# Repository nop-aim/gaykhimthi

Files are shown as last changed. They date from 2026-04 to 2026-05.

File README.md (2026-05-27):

# 🦯 Gậy Thông Minh – Smart Cane

> Thiết bị hỗ trợ người khiếm thị tích hợp AI nhận diện vật cản, cảnh báo âm thanh theo thời gian thực và nút SOS khẩn cấp.

---

## Mục lục

1. [Tổng quan dự án](#1-tổng-quan-dự-án)
2. [Kiến trúc hệ thống](#2-kiến-trúc-hệ-thống)
3. [Phần cứng](#3-phần-cứng)
4. [Phần mềm](#4-phần-mềm)
5. [Luồng hoạt động](#5-luồng-hoạt-động)
6. [Hướng dẫn cài đặt](#6-hướng-dẫn-cài-đặt)
7. [Cấu hình](#7-cấu-hình)
8. [Giao thức truyền thông](#8-giao-thức-truyền-thông)
9. [Xử lý lỗi và cơ chế an toàn](#9-xử-lý-lỗi-và-cơ-chế-an-toàn)
10. [Cấu trúc thư mục](#10-cấu-trúc-thư-mục)

---

## 1. Tổng quan dự án

**Gậy Thông Minh** là thiết bị hỗ trợ điều hướng cho người khiếm thị, hoạt động theo mô hình **Edge–Cloud Hybrid**:

- **Trên gậy (Edge – XIAO ESP32-S3):** chụp ảnh liên tục, đọc cảm biến siêu âm, phát âm thanh cảnh báo qua loa I2S, theo dõi GPS và gửi SMS khẩn cấp.
- **Máy tính xách tay / máy chủ (Cloud – Python/Flask):** nhận ảnh từ ESP32, chạy mô hình YOLO11 để nhận diện vật cản, trả kết quả cảnh báo bằng tiếng Việt và phát âm thanh TTS trên màn hình.

Hai tầng kết nối với nhau qua WiFi nội bộ bằng HTTP REST.

---

## 2. Kiến trúc hệ thống

```
┌──────────────────────────────────────────────────────────┐
│                  XIAO ESP32-S3 (trên gậy)                │
│                                                          │
│  ┌──────────┐   JPEG    ┌──────────────────────────────┐ │
│  │ Camera   │ ────────► │  TaskCamera (Core 0)         │ │
│  │ OV2640   │           │  POST /upload → nhận WARNING │ │
│  └──────────┘           └──────────────────────────────┘ │
│                                        │ mutex           │
│  ┌──────────┐  I2C      ┌──────────────▼──────────────┐  │
│  │ Siêu âm  │ ────────► │  TaskSensors (Core 1)       │  │
│  │ SRF02    │           │  Đọc khoảng cách + playAlert│  │
│  └──────────┘           └─────────────────────────────┘  │
│                                                          │
│  ┌──────────┐  UART     ┌──────────────────────────────┐ │
│  │  GPS     │ ────────► │  TaskGPS (Core 1)            │ │
│  │ NEO-6M   │           │  POST /gps mỗi 5 giây        │ │
│  └──────────┘           └──────────────────────────────┘ │
│                                                          │
│  ┌──────────┐  GPIO     ┌──────────────────────────────┐ │
│  │ Nút SOS  │ ────────► │  Gửi SMS + playAlert(SOS)    │ │
│  └──────────┘           └──────────────────────────────┘ │
│                                                          │
│  ┌──────────┐  UART     ┌──────────────────────────────┐ │
│  │ SIM A7680│ ◄──────── │  sendSMS() + sendAT()        │ │
│  └──────────┘           └──────────────────────────────┘ │
└──────────────────────────────────────────────────────────┘
                        │ WiFi (HTTP)
                        ▼
┌──────────────────────────────────────────────────────────┐
│              Server Python / Flask (máy tính)            │
│                                                          │
│  POST /upload ──► img_queue ──► ai_processing_thread     │
│                                  │                       │
│                                  ├─ YOLO11 inference     │
│                                  ├─ Xác định vị trí +    │
│                                  │  khoảng cách          │
│                                  ├─ gTTS → pygame TTS    │
│                                  └─ Trả [[WARNING_TEXT]] │
│                                                          │
│  POST /gps ─────────────────────► Lưu / hiển thị GPS     │
└──────────────────────────────────────────────────────────┘
```

---

## 3. Phần cứng

### 3.1 Danh sách linh kiện

| Linh kiện | Model | Giao tiếp | Vai trò |
|---|---|---|---|
| Vi điều khiển | Seeed XIAO ESP32-S3 Sense | — | Não xử lý trung tâm |
| Camera | OV2640 (tích hợp sẵn) | DVP parallel | Chụp ảnh QVGA JPEG |
| Cảm biến siêu âm | SRF02 (I2C, addr `0x70`) | I2C | Đo khoảng cách < 2 m |
| Module GPS | NEO-6M (hoặc tương đương) | UART1 (RX=3, TX=2) | Lấy toạ độ thời gian thực |
| Module SIM | SIM A7680C (4G LTE) | UART2 (RX=4, TX=1) | Gửi SMS SOS |
| Loa I2S | MAX98357A hoặc tương đương | I2S (BCK=7, WS=8, DATA=9) | Phát âm thanh cảnh báo |
| Nút bấm | Nút thường hở (NO) | GPIO 44 (INPUT_PULLUP) | Kích hoạt SOS |

### 3.2 Sơ đồ chân (XIAO ESP32-S3)

| GPIO | Tên chân | Kết nối |
|---|---|---|
| 5 | SDA | I2C SDA (cảm biến siêu âm) |
| 6 | SCL | I2C SCL (cảm biến siêu âm) |
| 7 | I2S_BCK | Loa I2S – Bit Clock |
| 8 | I2S_WS | Loa I2S – Word Select (LRCK) |
| 9 | I2S_DATA | Loa I2S – Data |
| 44 | BUTTON | Nút SOS (GND khi nhấn) |
| 1 | TX2 | SIM A7680C RX |
| 4 | RX2 | SIM A7680C TX |
| 2 | TX1 | GPS TX |
| 3 | RX1 | GPS RX |

> **Lưu ý:** Camera OV2640 sử dụng các chân DVP cố định theo cấu hình XIAO ESP32-S3 Sense (D0–D7, XCLK, PCLK, VSYNC, HREF, SIOD, SIOC) — không thay đổi được.

---

## 4. Phần mềm

### 4.1 Firmware ESP32 (`esp32_improved.ino`)

Viết bằng **Arduino framework** cho ESP32, sử dụng **FreeRTOS** để chạy đa nhiệm trên 2 nhân CPU.

| Task | Nhân | Stack | Chức năng |
|---|---|---|---|
| `TaskCamera` | Core 0 | 16 KB | Chụp ảnh → POST lên server → nhận cảnh báo AI |
| `TaskSensors` | Core 1 | 10 KB | Đọc siêu âm I2C, xử lý nút SOS, phát âm thanh |
| `TaskGPS` | Core 1 | 8 KB | Đọc GPS NMEA, gửi toạ độ lên server mỗi 5 giây |

**Thư viện Arduino cần thiết:**

- `esp_camera.h` — driver camera ESP32
- `WiFi.h` + `HTTPClient.h` — kết nối mạng
- `Wire.h` — giao tiếp I2C với cảm biến siêu âm
- `TinyGPS++` — giải mã dữ liệu NMEA từ module GPS
- `AudioTools` — tạo sóng sin và xuất I2S cho loa

### 4.2 Server AI (`serve_2.py`)

Viết bằng **Python 3**, chạy trên máy tính trong cùng mạng WiFi.

**Thư viện Python cần thiết:**

- `flask` — HTTP server nhận ảnh từ ESP32
- `ultralytics` — chạy mô hình YOLO11
- `opencv-python` (`cv2`) — giải mã JPEG, hiển thị kết quả
- `numpy` — xử lý mảng ảnh
- `gTTS` — chuyển text thành giọng nói tiếng Việt
- `pygame` — phát âm thanh TTS
- `threading`, `queue` — xử lý bất đồng bộ

---

## 5. Luồng hoạt động

### 5.1 Nhận diện vật cản bằng AI (Camera + YOLO)

```
ESP32                              Server (Flask + YOLO)
  │                                        │
  ├─ Chụp ảnh QVGA JPEG (300ms/lần)        │
  ├─ POST /upload (raw bytes)  ──────────► │
  │                                        ├─ Giải mã JPEG → frame
  │                                        ├─ YOLO11 inference (conf=0.5)
  │                                        ├─ Lọc class: người, xe, ghế, bàn...
  │                                        ├─ Tính vị trí (trái/trước/phải)
  │                                        ├─ Tính khoảng cách (% diện tích bbox)
  │                                        ├─ Tạo chuỗi: "Có ô tô phía trước, rất gần"
  │                                        ├─ gTTS phát tiếng (nếu cảnh báo mới)
  │ ◄────────────────── [[WARNING_TEXT]]   │
  ├─ Cập nhật `hasObstacle_AI`             │
  ├─ Phát beep I2S (1500Hz, 400ms)         │
```

**Logic xác định khoảng cách** (dựa vào tỉ lệ diện tích bounding box / tổng diện tích frame):

| Tỉ lệ diện tích | Cảnh báo |
|---|---|
| > 35% | "rất gần"|
| 12% – 35% | "đang đến gần" |
| < 12% | "ở xa" |

**Các lớp vật thể được nhận diện:**

| ID COCO | Tên tiếng Anh | Tên tiếng Việt|
|---|---|---|
| 0 | person | người |
| 1 | bicycle | xe đạp |
| 2 | car | ô tô |
| 3 | motorcycle | xe máy |
| 5 | bus | xe buýt |
| 7 | truck | xe tải |
| 56 | chair | ghế |
| 60 | dining table | bàn |

### 5.2 Cảm biến siêu âm (khoảng cách gần)

- Đọc liên tục qua I2C (địa chỉ `0x70`)
- Áp dụng bộ lọc trung bình trượt 5 mẫu để giảm nhiễu
- Nếu khoảng cách trung bình < **120 cm**: kích hoạt cờ `hasObstacle_US`
- Phát âm thanh beep khẩn (2000 Hz, 150 ms) — **ưu tiên cao hơn cảnh báo AI**

### 5.3 SOS khẩn cấp

1. Người dùng nhấn nút GPIO 44
2. Debounce 3 giây (tránh gửi nhiều lần)
3. Gửi SMS đến số `SOS_PHONE` qua SIM A7680C:
   ```
   SOS! Vi tri: https://maps.google.com/?q=<lat>,<lng>
   ```
4. Phát âm thanh cảnh báo (1500 Hz, 1000 ms)

### 5.4 GPS tracking

- Task `TaskGPS` chạy riêng trên Core 1, không block cảm biến siêu âm
- Giải mã dữ liệu NMEA từ module GPS qua UART1
- Cần tối thiểu **4 vệ tinh** để coi là tín hiệu hợp lệ
- Gửi toạ độ JSON lên `POST /gps` mỗi **5 giây**:
  ```json
  {"lat": 10.762622, "lng": 106.660172}
  ```

---

## 6. Hướng dẫn cài đặt

### 6.1 Cài đặt Server (máy tính)

```bash
# 1. Tạo môi trường ảo Python
python -m venv venv
source venv/bin/activate       # Linux/macOS
venv\Scripts\activate          # Windows

# 2. Cài đặt thư viện
pip install flask ultralytics opencv-python gTTS pygame numpy

# 3. Tải mô hình YOLO11s (tự động tải khi chạy lần đầu)
#    Hoặc tải thủ công: https://github.com/ultralytics/assets/releases
#    Đặt file yolo11s.pt cùng thư mục với serve_2.py

# 4. Chạy server
python serve_2.py
# Server sẽ lắng nghe tại http://0.0.0.0:5000
```

### 6.2 Nạp firmware ESP32

**Yêu cầu:**
- Arduino IDE 2.x hoặc VS Code + PlatformIO
- Board: `Seeed XIAO ESP32S3` (cài qua Board Manager)

**Thư viện cần cài (Library Manager):**
- `TinyGPS++` by Mikal Hart
- `arduino-audio-tools` by pschatzmann

**Bước nạp:**
1. Mở `esp32_improved.ino` trong Arduino IDE
2. Cập nhật cấu hình mạng (xem mục 7)
3. Chọn **Board:** `XIAO_ESP32S3` và **Port** tương ứng
4. Nhấn **Upload**

---

## 7. Cấu hình

Tất cả cấu hình nằm ở đầu file `esp32_improved.ino`:

```cpp
// ── Mạng & Server ────────────────────────────────────────
const char* serverUrl = "http://192.168.1.135:5000/upload"; // IP máy chủ
const char* gpsUrl    = "http://192.168.1.135:5000/gps";    // Endpoint GPS
const char* ssid      = "Tên_WiFi";                         // SSID WiFi
const char* password  = "Mật_khẩu_WiFi";                   // Mật khẩu WiFi

// ── SOS ──────────────────────────────────────────────────
const char* SOS_PHONE = "09xxxxxxxx";                       // Số điện thoại nhận SMS

// ── Ngưỡng cảm biến siêu âm ──────────────────────────────
// Trong TaskSensors: (sum / filterSamples) < 120
// 120 tương đương ~1.2 m (đơn vị cảm biến SRF02: cm)
// Thay đổi giá trị này để điều chỉnh độ nhạy

// ── Tần suất chụp ảnh ────────────────────────────────────
vTaskDelay(300 / portTICK_PERIOD_MS); // 300ms ≈ ~3 fps
```

**Tìm IP máy chủ** (máy chạy `serve_2.py`):
```bash
# Linux/macOS
ip addr show | grep "inet "

# Windows
ipconfig
```

---

## 8. Giao thức truyền thông

### POST `/upload` — Gửi ảnh từ ESP32

| Thuộc tính | Giá trị |
|---|---|
| Method | POST |
| Content-Type | `image/jpeg` |
| Body | Raw JPEG bytes |
| Response | `[[CLEAR]]` hoặc `[[Có ô tô phía trước, rất gần]]` |

### POST `/gps` — Gửi toạ độ GPS

| Thuộc tính | Giá trị |
|---|---|
| Method | POST |
| Content-Type | `application/json` |
| Body | `{"lat": 10.762622, "lng": 106.660172}` |

---

## 9. Xử lý lỗi và cơ chế an toàn

| Vấn đề | Giải pháp đã triển khai |
|---|---|
| WiFi mất kết nối | `connectWiFi()` tự động thử lại; watchdog kiểm tra mỗi 30 giây trong `loop()` |
| HTTP timeout | Mọi request đều có timeout 3 giây (`HTTP_TIMEOUT_MS`) |
| Race condition giữa 2 core | FreeRTOS mutex (`obstacleMutex`) bảo vệ biến dùng chung |
| GPS block siêu âm | `TaskGPS` chạy tách biệt trên Core 1 |
| Nút SOS nhấn nhiều lần | Debounce phần mềm 3 giây (`lastSosTap`) |
| Loa block CPU | `playAlert()` dùng timeout + `taskYIELD()` thay vì busy-wait |
| FreeRTOS watchdog reset | Thay `delay()` bằng `vTaskDelay()` trong tất cả task |
| SIM không nhận lệnh | `readSIM()` chờ prompt `>` trước khi gửi nội dung SMS |
| Bộ lọc nhiễu siêu âm | Trung bình trượt 5 mẫu (`filterSamples = 5`) |
| TTS phát liên tục | Cooldown 3 giây (`last_speak_time`) giữa các lần phát |
| Hàng đợi ảnh tràn | `img_queue` kích thước 1, tự xoá frame cũ khi đầy |

---

## 10. Cấu trúc thư mục

```
smart-cane/
├── esp32_improved.ino   # Firmware XIAO ESP32-S3
├── serve_2.py           # Server AI Flask + YOLO11
├── yolo11s.pt           # Mô hình YOLO11s (tải riêng)
└── README.md            # Tài liệu này
```

---

## Tác giả & Giấy phép

Dự án được phát triển nhằm mục đích hỗ trợ người khiếm thị. Mã nguồn mở để học tập và cải tiến.

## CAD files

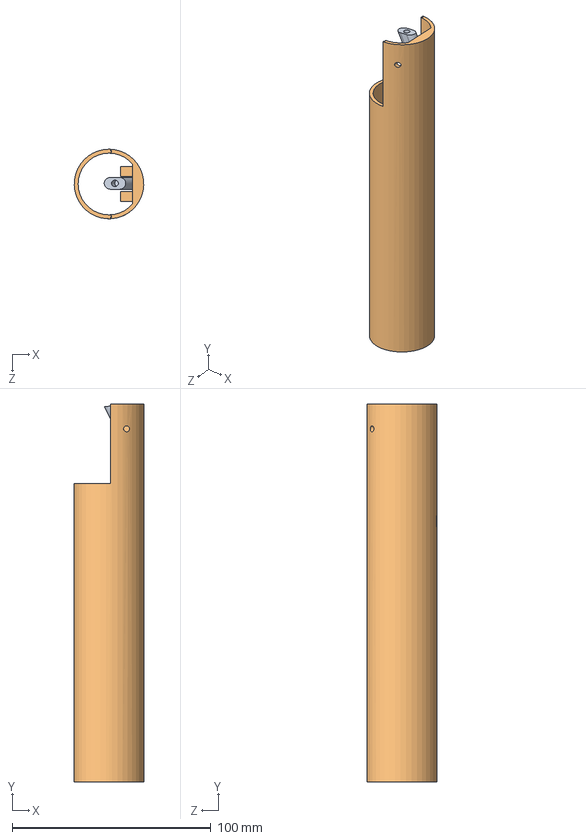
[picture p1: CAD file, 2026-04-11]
STL/Assem1.SLDASM
35.0 x 190.0 x 35.0 mm
end_2
gy

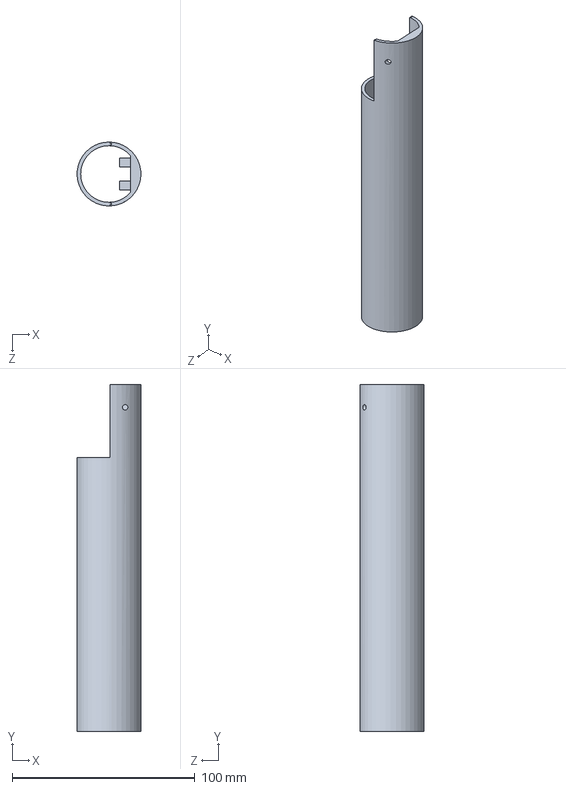
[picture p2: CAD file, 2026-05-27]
STL/end_2.SLDPRT
35.0 x 190.0 x 35.0 mm

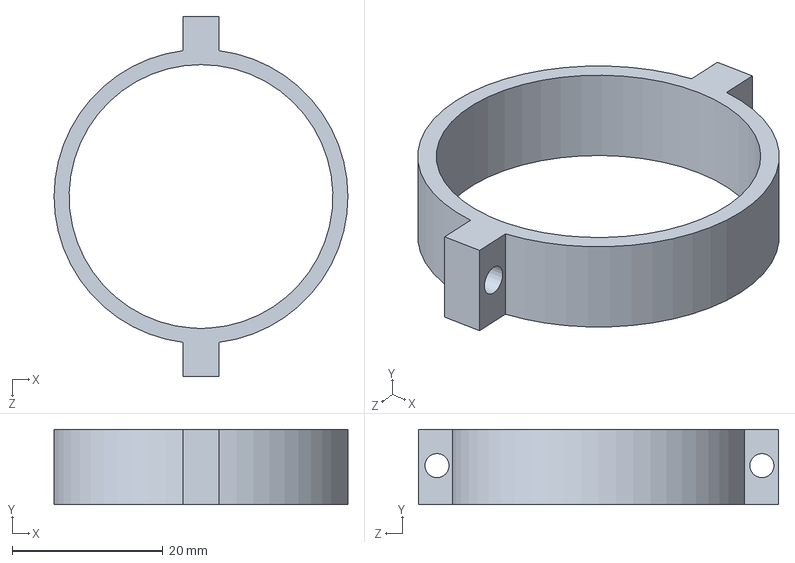
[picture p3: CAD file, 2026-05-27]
STL/khopnoi.SLDPRT
39.0 x 10.0 x 47.8 mm

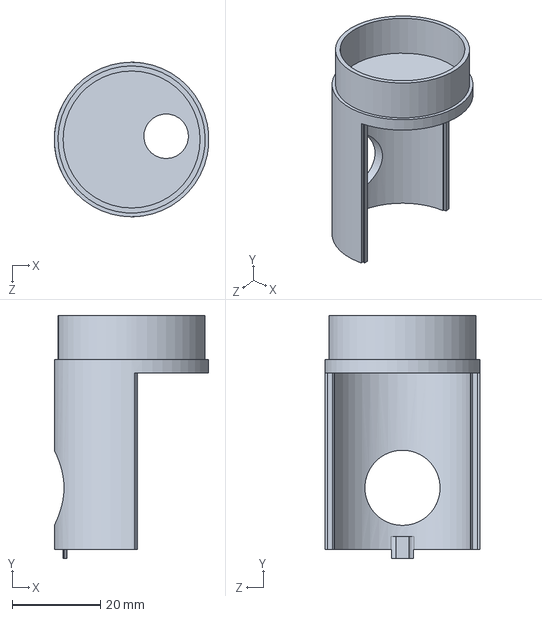
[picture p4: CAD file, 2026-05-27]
STL/end_khopnoi.SLDPRT
35.0 x 55.0 x 35.0 mm

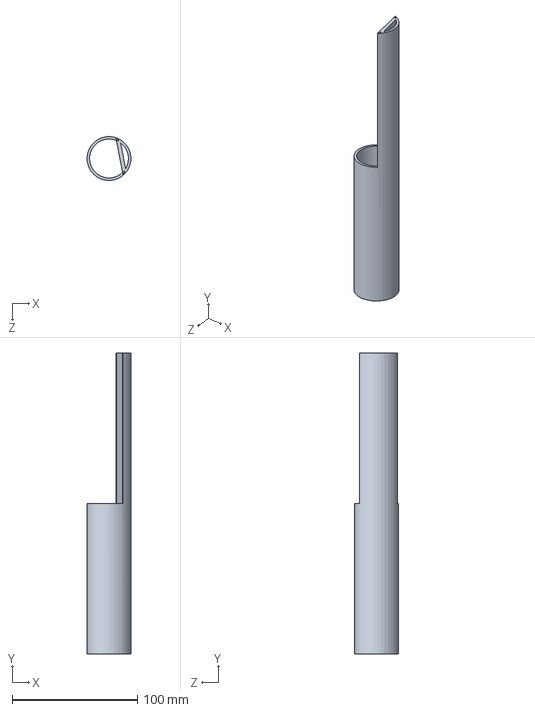
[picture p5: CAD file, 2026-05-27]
STL/header.SLDPRT
35.0 x 240.0 x 35.0 mm

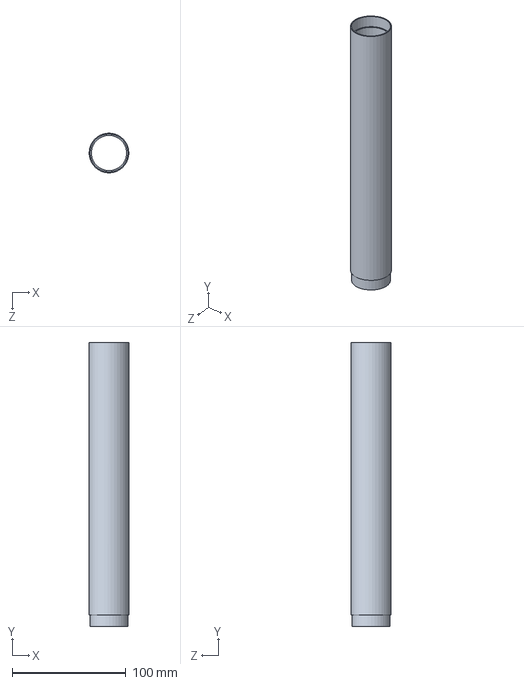
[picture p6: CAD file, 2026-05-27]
STL/body.SLDPRT
35.0 x 250.0 x 35.0 mm

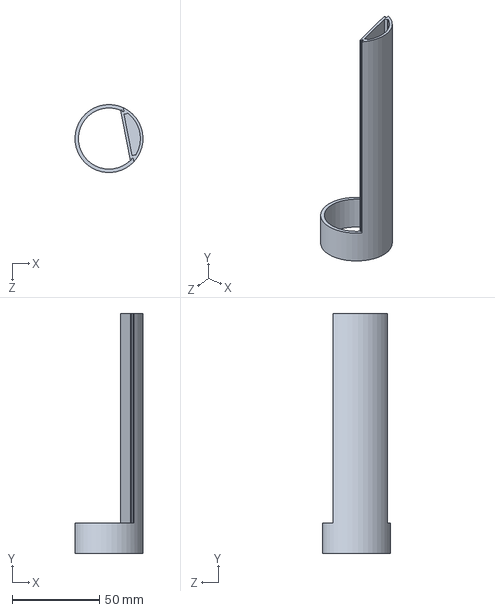
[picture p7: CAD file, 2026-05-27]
STL/header_cap_napday.SLDPRT
39.0 x 137.5 x 38.9 mm

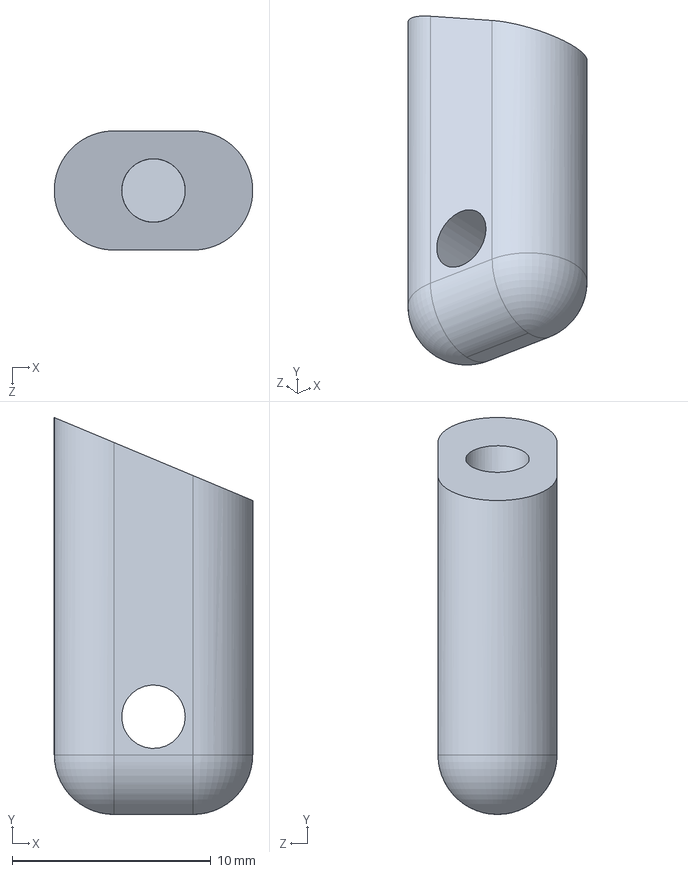
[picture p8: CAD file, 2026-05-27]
STL/gy.SLDPRT
10.0 x 20.0 x 6.00 mm

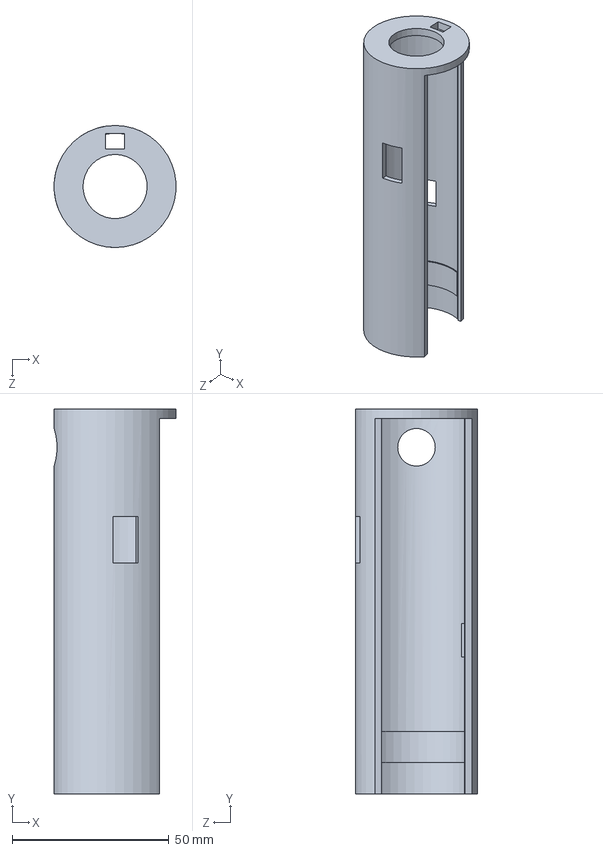
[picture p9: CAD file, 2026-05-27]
STL/header_cap.SLDPRT
38.9 x 123.0 x 39.0 mm

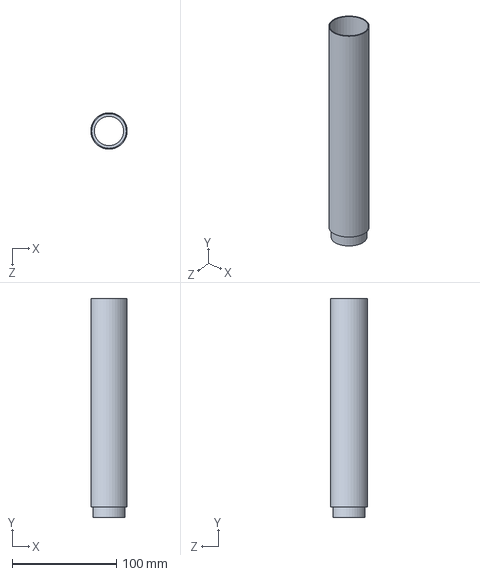
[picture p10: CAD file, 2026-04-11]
STL/bodyhead.SLDPRT
34.9 x 210.0 x 35.0 mm

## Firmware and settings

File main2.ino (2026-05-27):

#include "esp_camera.h"
#include <WiFi.h>
#include <HTTPClient.h>
#include <Wire.h>
#include <TinyGPS++.h>
#include "AudioTools.h"

// ════════════════════════════════════════════════════════════════
//  CẤU HÌNH
// ════════════════════════════════════════════════════════════════
const char* serverUrl = "http://192.168.1.135:5000/upload";
const char* gpsUrl    = "http://192.168.1.135:5000/gps";
const char* ssid      = "TMaii";
const char* password  = "16071779@";
const char* SOS_PHONE = "0397969813";

#define PIN_SDA        5
#define PIN_SCL        6
#define PIN_I2S_BCK    7
#define PIN_I2S_WS     8
#define PIN_I2S_DATA   9
#define PIN_BUTTON    44
#define HTTP_TIMEOUT_MS 3000    // [FIX 1] Timeout cho mọi request HTTP

// ════════════════════════════════════════════════════════════════
//  CAMERA PINS (XIAO ESP32-S3 SENSE)
// ════════════════════════════════════════════════════════════════
#define PWDN_GPIO_NUM  -1
#define RESET_GPIO_NUM -1
#define XCLK_GPIO_NUM  10
#define SIOD_GPIO_NUM  40
#define SIOC_GPIO_NUM  39
#define Y9_GPIO_NUM    48
#define Y8_GPIO_NUM    11
#define Y7_GPIO_NUM    12
#define Y6_GPIO_NUM    14
#define Y5_GPIO_NUM    16
#define Y4_GPIO_NUM    18
#define Y3_GPIO_NUM    17
#define Y2_GPIO_NUM    15
#define VSYNC_GPIO_NUM 38
#define HREF_GPIO_NUM  47
#define PCLK_GPIO_NUM  13

// ════════════════════════════════════════════════════════════════
//  OBJECTS
// ════════════════════════════════════════════════════════════════
HardwareSerial SIM(2);
HardwareSerial GPS_Serial(1);
TinyGPSPlus gps;
I2SStream i2s;
SineWaveGenerator<int16_t> sineWave;
GeneratedSoundStream<int16_t> sound(sineWave);

// [FIX 3] Mutex bảo vệ biến dùng chung giữa 2 core
SemaphoreHandle_t obstacleMutex;
volatile bool hasObstacle_AI = false;
volatile bool hasObstacle_US = false;
String ai_warning_msg = "";
String currentGPS     = "0,0";

// Bộ lọc siêu âm
const int filterSamples = 5;
int distanceHistory[filterSamples] = {0};
int historyIndex = 0;

// Timers
unsigned long lastGPSSend  = 0;
unsigned long lastSosTap   = 0;   // [FIX 4] debounce SOS

// ════════════════════════════════════════════════════════════════
//  SETUP
// ════════════════════════════════════════════════════════════════
void setup() {
  Serial.begin(115200);
  delay(2000);
  Serial.println("\n=== KHOI DONG GAY THONG MINH (XIAO S3) ===");

  // [FIX 3] Tạo mutex trước mọi task
  obstacleMutex = xSemaphoreCreateMutex();

  // 1. I2C
  Wire.begin(PIN_SDA, PIN_SCL);
  Wire.setClock(100000);

  // 2. SIM A7680C
  SIM.begin(115200, SERIAL_8N1, 4, 1);
  delay(2000);
  sendAT("AT");
  sendAT("AT+CPIN?");
  sendAT("AT+CSQ");
  sendAT("AT+CNMP=38");
  sendAT("AT+AUTOCONN=1");
  delay(3000);

  // 3. GPS
  GPS_Serial.begin(9600, SERIAL_8N1, 3, 2);
  Serial.println("Dang cho GPS fix...");
  unsigned long start = millis();
  while (millis() - start < 20000) {
    while (GPS_Serial.available()) gps.encode(GPS_Serial.read());
    if (gps.location.isValid() && gps.satellites.value() >= 4) {
      Serial.printf("\n[ OK ] GPS: %.6f, %.6f (%d sats)\n",
                    gps.location.lat(), gps.location.lng(), gps.satellites.value());
      break;
    }
    Serial.print(".");
    delay(500);
  }

  // 4. Camera
  camera_config_t config;
  config.ledc_channel = LEDC_CHANNEL_0;
  config.ledc_timer   = LEDC_TIMER_0;
  config.pin_d0 = Y2_GPIO_NUM; config.pin_d1 = Y3_GPIO_NUM;
  config.pin_d2 = Y4_GPIO_NUM; config.pin_d3 = Y5_GPIO_NUM;
  config.pin_d4 = Y6_GPIO_NUM; config.pin_d5 = Y7_GPIO_NUM;
  config.pin_d6 = Y8_GPIO_NUM; config.pin_d7 = Y9_GPIO_NUM;
  config.pin_xclk    = XCLK_GPIO_NUM;  config.pin_pclk  = PCLK_GPIO_NUM;
  config.pin_vsync   = VSYNC_GPIO_NUM; config.pin_href  = HREF_GPIO_NUM;
  config.pin_sscb_sda = SIOD_GPIO_NUM; config.pin_sscb_scl = SIOC_GPIO_NUM;
  config.pin_pwdn  = PWDN_GPIO_NUM;    config.pin_reset = RESET_GPIO_NUM;
  config.xclk_freq_hz = 20000000;
  config.frame_size   = FRAMESIZE_QVGA;
  config.pixel_format = PIXFORMAT_JPEG;
  config.grab_mode    = CAMERA_GRAB_LATEST;
  config.fb_count     = 2;
  config.jpeg_quality = 12;

  esp_err_t err = esp_camera_init(&config);
  if (err == ESP_OK) {
    sensor_t* s = esp_camera_sensor_get();
    s->set_hmirror(s, 1);
    s->set_vflip(s, 0);
    Serial.println("[ OK ] Camera san sang.");
  } else {
    Serial.printf("[ FAIL ] Camera loi: 0x%x\n", err);
  }

  // 5. WiFi
  pinMode(PIN_BUTTON, INPUT_PULLUP);
  connectWiFi();

  // 6. Loa I2S
  auto info = i2s.defaultConfig();
  info.sample_rate = 44100;
  info.pin_bck     = PIN_I2S_BCK;
  info.pin_ws      = PIN_I2S_WS;
  info.pin_data    = PIN_I2S_DATA;
  i2s.begin(info);

  // Tạo tasks — Stack size tăng thêm do thêm xử lý
  xTaskCreatePinnedToCore(TaskCamera,  "TaskCam",  16000, NULL, 1, NULL, 0);
  xTaskCreatePinnedToCore(TaskSensors, "TaskSens", 10000, NULL, 1, NULL, 1);
  xTaskCreatePinnedToCore(TaskGPS,     "TaskGPS",   8000, NULL, 1, NULL, 1);
}

// ════════════════════════════════════════════════════════════════
//  [FIX 5] Tự động kết nối lại WiFi
// ════════════════════════════════════════════════════════════════
void connectWiFi() {
  if (WiFi.status() == WL_CONNECTED) return;
  WiFi.begin(ssid, password);
  Serial.print("Connecting WiFi");
  int retry = 0;
  while (WiFi.status() != WL_CONNECTED && retry < 20) {
    delay(500);
    Serial.print(".");
    retry++;
  }
  if (WiFi.status() == WL_CONNECTED)
    Serial.println("\n[ OK ] IP: " + WiFi.localIP().toString());
  else
    Serial.println("\n[ WARN ] WiFi timeout, se thu lai sau.");
}

// ════════════════════════════════════════════════════════════════
//  CORE 0: CAMERA & UPLOAD
// ════════════════════════════════════════════════════════════════
void TaskCamera(void* p) {
  for (;;) {
    // [FIX 5] Kiểm tra và reconnect WiFi nếu cần
    if (WiFi.status() != WL_CONNECTED) {
      Serial.println("!!! WiFi mat ket noi — dang thu lai...");
      connectWiFi();
      vTaskDelay(2000 / portTICK_PERIOD_MS);
      continue;
    }

    camera_fb_t* fb = esp_camera_fb_get();
    if (!fb) {
      Serial.println("!!! Camera Capture Failed");
      vTaskDelay(100 / portTICK_PERIOD_MS);
      continue;
    }

    HTTPClient http;
    http.begin(serverUrl);
    http.addHeader("Content-Type", "image/jpeg");
    http.setTimeout(HTTP_TIMEOUT_MS);   // [FIX 1]

    int httpCode = http.POST(fb->buf, fb->len);

    if (httpCode == 200) {
      String response = http.getString();
      int s = response.indexOf("[[");
      int e = response.indexOf("]]");
      if (s != -1 && e != -1) {
        String cleanRes = response.substring(s + 2, e);
        cleanRes.trim();

        // [FIX 3] Dùng mutex khi ghi biến dùng chung
        if (xSemaphoreTake(obstacleMutex, pdMS_TO_TICKS(10)) == pdTRUE) {
          if (cleanRes != "CLEAR") {
            ai_warning_msg  = cleanRes;
            hasObstacle_AI  = true;
          } else {
            hasObstacle_AI  = false;
          }
          xSemaphoreGive(obstacleMutex);
        }
      }
    } else if (httpCode < 0) {
      Serial.printf("!!! HTTP loi: %d\n", httpCode);
    }

    http.end();
    esp_camera_fb_return(fb);
    vTaskDelay(300 / portTICK_PERIOD_MS);
  }
}

// ════════════════════════════════════════════════════════════════
//  [FIX 2] CORE 1 - TASK GPS RIÊNG (không block siêu âm)
// ════════════════════════════════════════════════════════════════
void TaskGPS(void* p) {
  for (;;) {
    while (GPS_Serial.available() > 0) {
      if (gps.encode(GPS_Serial.read()) && gps.location.isValid()) {
        currentGPS = String(gps.location.lat(), 6) + "," + String(gps.location.lng(), 6);
      }
    }

    // Gửi GPS mỗi 5 giây
    if (millis() - lastGPSSend > 5000 && gps.location.isValid()
        && WiFi.status() == WL_CONNECTED) {
      HTTPClient httpGPS;
      httpGPS.begin(gpsUrl);
      httpGPS.addHeader("Content-Type", "application/json");
      httpGPS.setTimeout(HTTP_TIMEOUT_MS);  // [FIX 1]
      String payload = "{\"lat\":" + String(gps.location.lat(), 6) +
                       ",\"lng\":" + String(gps.location.lng(), 6) + "}";
      httpGPS.POST(payload);
      httpGPS.end();
      lastGPSSend = millis();
    }

    vTaskDelay(200 / portTICK_PERIOD_MS);
  }
}

// ════════════════════════════════════════════════════════════════
//  CORE 1: CẢM BIẾN SIÊU ÂM & ÂM THANH
// ════════════════════════════════════════════════════════════════
void TaskSensors(void* p) {
  for (;;) {
    // ── Siêu âm I2C ──────────────────────────────────────────────
    Wire.beginTransmission(0x70);
    Wire.write(0x51);
    Wire.endTransmission();
    vTaskDelay(70 / portTICK_PERIOD_MS);

    Wire.requestFrom(0x70, 2);
    if (Wire.available() >= 2) {
      int rawDist = (Wire.read() << 8) | Wire.read();
      if (rawDist > 0 && rawDist < 4000) { // lấy khoảng từ 0-4m
        distanceHistory[historyIndex] = rawDist;
        historyIndex = (historyIndex + 1) % filterSamples;
        long sum = 0;
        for (int i = 0; i < filterSamples; i++) sum += distanceHistory[i];
        if ((sum / filterSamples) < 120) { //120 là 2m
          // [FIX 3] mutex khi ghi
          if (xSemaphoreTake(obstacleMutex, pdMS_TO_TICKS(10)) == pdTRUE) {
            hasObstacle_US = true;
            xSemaphoreGive(obstacleMutex);
          }
        }
      }
    }

    // ── [FIX 4] Nút SOS có debounce 3 giây ──────────────────────
    if (digitalRead(PIN_BUTTON) == LOW) {
      unsigned long now = millis();
      if (now - lastSosTap > 3000) {
        lastSosTap = now;
        sendSMS(SOS_PHONE, "SOS! Vi tri: https://maps.google.com/?q=" + currentGPS);
        playAlert(1500, 1000);
      }
    }

    // ── Ưu tiên cảnh báo âm thanh ────────────────────────────────
    bool doUS = false, doAI = false;
    String warnCopy;

    // [FIX 3] Đọc cờ trong mutex, sau đó xử lý ngoài
    if (xSemaphoreTake(obstacleMutex, pdMS_TO_TICKS(10)) == pdTRUE) {
      if (hasObstacle_US) { doUS = true; hasObstacle_US = false; }
      else if (hasObstacle_AI) { doAI = true; warnCopy = ai_warning_msg; hasObstacle_AI = false; }
      xSemaphoreGive(obstacleMutex);
    }

    // [FIX 6] playAlert chạy trong scope nhỏ, không lock mutex
    if (doUS) {
      Serial.println(">>> CANH BAO: SIEU AM!");
      playAlert(2000, 150);
    } else if (doAI) {
      Serial.println(">>> AI WARNING: " + warnCopy);
      playAlert(1500, 400);
    }

    vTaskDelay(30 / portTICK_PERIOD_MS);
  }
}

// ════════════════════════════════════════════════════════════════
//  TIỆN ÍCH
// ════════════════════════════════════════════════════════════════

// [FIX 6] playAlert dùng timeout thay vì while(busy) để không block lâu
void playAlert(int freq, int duration) {
  sineWave.begin(2, 44100, freq);   // Tăng volume nhẹ (5→8)
  unsigned long stop = millis() + duration;
  while (millis() < stop) {
    StreamCopy copier(i2s, sound);
    copier.copy();
    // Nhường CPU trong 1 tick để OS có thể xử lý task khác nếu cần
    taskYIELD();
  }
  i2s.flush();
}

// ── Hàm phụ: đọc response từ SIM trong timeout ───────────────
String readSIM(unsigned long timeoutMs) {
  String resp = "";
  unsigned long t = millis();
  while (millis() - t < timeoutMs) {
    while (SIM.available()) {
      char c = SIM.read();
      resp += c;
    }
    // Thoát sớm nếu đã có OK, ERROR hoặc dấu >
    if (resp.indexOf("OK") != -1  ||
        resp.indexOf("ERROR") != -1 ||
        resp.indexOf(">") != -1) break;
    vTaskDelay(10 / portTICK_PERIOD_MS);
  }
  return resp;
}

// ── Gửi SMS ──────────────────────────────────────────────────
void sendSMS(String phone, String msg) {
  Serial.println(">>> GUI SMS: " + phone);

  // Lỗi 1 cũ: delay 100ms không đủ cho CMGF
  SIM.println("AT+CMGF=1");
  String r1 = readSIM(1000);
  if (r1.indexOf("OK") == -1) {
    Serial.println("!!! CMGF that bai: " + r1);
    return;  // Không gửi nếu chế độ text chưa được bật
  }

  // Lỗi 2 cũ: delay 100ms không đủ + không đọc prompt
  SIM.printf("AT+CMGS=\"%s\"\r\n", phone.c_str());

  // Phải chờ dấu ">" — SIM module mới sẵn sàng nhận nội dung
  String r2 = readSIM(5000);  // A7680C có thể mất ~2-3 giây
  if (r2.indexOf(">") == -1) {
    Serial.println("!!! Khong nhan duoc prompt '>': " + r2);
    return;
  }

  // Lỗi 3 cũ: delay 100ms giữa print và CTRL+Z không đủ
  SIM.print(msg);
  vTaskDelay(200 / portTICK_PERIOD_MS);  // Đợi SIM nhận xong nội dung
  SIM.write(26);  // CTRL+Z = ký tự ASCII 26, ra lệnh gửi

  // Chờ kết quả — CMGS: +CMGS: <mr> rồi OK
  String r3 = readSIM(10000);
  if (r3.indexOf("+CMGS:") != -1) {
    Serial.println(">>> SMS THANH CONG!");
  } else {
    Serial.println("!!! SMS THAT BAI: " + r3);
  }
}

// ── sendAT cũng cần dùng vTaskDelay thay vì delay() ─────────
// (delay() blocking trong task FreeRTOS gây watchdog reset!)
void sendAT(String cmd) {
  Serial.println(">>> " + cmd);
  SIM.println(cmd);
  vTaskDelay(1000 / portTICK_PERIOD_MS);  // Sửa: delay → vTaskDelay
  while (SIM.available()) Serial.write(SIM.read());
}

void loop() {
  // [FIX 5] Watchdog nhẹ: kiểm tra WiFi mỗi 30 giây
  static unsigned long lastWiFiCheck = 0;
  if (millis() - lastWiFiCheck > 30000) {
    lastWiFiCheck = millis();
    if (WiFi.status() != WL_CONNECTED) connectWiFi();
  }
  delay(1000);
}

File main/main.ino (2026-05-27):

#include "esp_camera.h"
#include <WiFi.h>
#include <HTTPClient.h>
#include <Wire.h>
#include <TinyGPS++.h>
#include "AudioTools.h"

// --- CẤU HÌNH HỆ THỐNG ---
const char* serverUrl = "http://192.168.100.130:5000/upload";
const char* ssid = "Minion";
const char* password = "20042007";

#define PIN_SDA 5
#define PIN_SCL 6
#define PIN_I2S_BCK 7
#define PIN_I2S_WS 8
#define PIN_I2S_DATA 9
#define PIN_BUTTON 6 

HardwareSerial SIM(2); 
HardwareSerial GPS_Serial(1);
TinyGPSPlus gps;
I2SStream i2s;
SineWaveGenerator<int16_t> sineWave;
GeneratedSoundStream<int16_t> sound(sineWave);

bool hasObstacle_AI = false;
bool hasObstacle_US = false;
String currentGPS = "0,0";

const int filterSamples = 5;
int distanceHistory[filterSamples];
int historyIndex = 0;

// --- CẤU HÌNH CAMERA XIAO S3 ---
#define PWDN_GPIO_NUM  -1
#define RESET_GPIO_NUM -1
#define XCLK_GPIO_NUM   10
#define SIOD_GPIO_NUM   40
#define SIOC_GPIO_NUM   39
#define Y9_GPIO_NUM     48
#define Y8_GPIO_NUM     11
#define Y7_GPIO_NUM     12
#define Y6_GPIO_NUM     14
#define Y5_GPIO_NUM     16
#define Y4_GPIO_NUM     18
#define Y3_GPIO_NUM     17
#define Y2_GPIO_NUM     15
#define VSYNC_GPIO_NUM 38
#define HREF_GPIO_NUM   47
#define PCLK_GPIO_NUM   13

void setup() {
  Serial.begin(115200);
  vTaskDelay(2000 / portTICK_PERIOD_MS);
  Serial.println("\n--- KHOI DONG HE THONG GAY THONG MINH ---");

  // 1. Kiểm tra I2C & Siêu âm
  Wire.begin(PIN_SDA, PIN_SCL);
  Wire.setClock(100000); 
  Wire.setTimeOut(50); 
  Wire.beginTransmission(0x70);
  if (Wire.endTransmission() == 0) Serial.println("[ OK ] Sieu am san sang.");
  else Serial.println("[ FAIL ] Loi ket noi Sieu am!");

  // 2. Kiểm tra SIM
  SIM.begin(115200, SERIAL_8N1, 4, 1);
  SIM.println("AT"); 
  unsigned long startSIM = millis();
  bool simOk = false;
  while (millis() - startSIM < 1500) {
    if (SIM.find("OK")) { simOk = true; break; }
  }
  if (simOk) Serial.println("[ OK ] Module SIM phan hoi.");
  else Serial.println("[ FAIL ] Module SIM khong phan hoi!");

  // 3. Khởi tạo GPS
  GPS_Serial.begin(9600, SERIAL_8N1, 3, 2);
  Serial.println("[ INFO ] GPS Serial khoi tao.");

  // 4. Khởi tạo Camera
  camera_config_t config;
  config.ledc_channel = LEDC_CHANNEL_0;
  config.ledc_timer = LEDC_TIMER_0;
  config.pin_d0 = Y2_GPIO_NUM; config.pin_d1 = Y3_GPIO_NUM;
  config.pin_d2 = Y4_GPIO_NUM; config.pin_d3 = Y5_GPIO_NUM;
  config.pin_d4 = Y6_GPIO_NUM; config.pin_d5 = Y7_GPIO_NUM;
  config.pin_d6 = Y8_GPIO_NUM; config.pin_d7 = Y9_GPIO_NUM;
  config.pin_xclk = XCLK_GPIO_NUM; config.pin_pclk = PCLK_GPIO_NUM;
  config.pin_vsync = VSYNC_GPIO_NUM; config.pin_href = HREF_GPIO_NUM;
  config.pin_sscb_sda = SIOD_GPIO_NUM; config.pin_sscb_scl = SIOC_GPIO_NUM;
  config.pin_pwdn = PWDN_GPIO_NUM; config.pin_reset = RESET_GPIO_NUM;
  config.xclk_freq_hz = 20000000;
  config.frame_size = FRAMESIZE_QVGA;
  config.pixel_format = PIXFORMAT_JPEG;
  config.grab_mode = CAMERA_GRAB_LATEST;
  config.fb_count = 2;
  config.jpeg_quality = 12;

  esp_err_t err = esp_camera_init(&config); // Sửa lỗi khai báo err
  if (err == ESP_OK) {
    sensor_t * s = esp_camera_sensor_get();
    s->set_hmirror(s, 1);
    s->set_vflip(s, 1);
    Serial.println("[ OK ] Camera san sang.");
  } else {
    Serial.printf("[ FAIL ] Camera THAT BAI! Code: 0x%x\n", err);
  }

  // 5. Kết nối WiFi (Sửa lỗi thiếu lệnh begin và vòng lặp đợi)
  pinMode(PIN_BUTTON, INPUT_PULLUP);
  WiFi.begin(ssid, password);
  Serial.print("Dang ket noi WiFi");
  int retry = 0;
  while (WiFi.status() != WL_CONNECTED && retry < 20) { // Đợi tối đa 10 giây
    vTaskDelay(500 / portTICK_PERIOD_MS);
    Serial.print(".");
    retry++;
  }
  
  if (WiFi.status() == WL_CONNECTED) {
    Serial.println("\n[ OK ] WiFi IP: " + WiFi.localIP().toString());
  } else {
    Serial.println("\n[ FAIL ] WiFi khong the ket noi!");
  }

  // 6. Khởi tạo Loa
  auto info = i2s.defaultConfig();
  info.sample_rate = 44100;
  info.pin_bck = PIN_I2S_BCK;
  info.pin_ws = PIN_I2S_WS;
  info.pin_data = PIN_I2S_DATA;
  i2s.begin(info);
  Serial.println("[ OK ] Am thanh I2S san sang.");

  Serial.println("--- Bat dau cac Task ---");
  xTaskCreatePinnedToCore(TaskCamera, "TaskCam", 10240, NULL, 1, NULL, 0);
  xTaskCreatePinnedToCore(TaskSensors, "TaskSens", 10240, NULL, 1, NULL, 1);
}

// --- CORE 0: AI VISION ---
void TaskCamera(void * p) {
  for(;;) {
    if (WiFi.status() == WL_CONNECTED) {
      camera_fb_t * fb = esp_camera_fb_get();
      if (fb) {
        HTTPClient http;
        http.begin(serverUrl);
        int httpCode = http.POST(fb->buf, fb->len);
        
        if (httpCode == 200) {
          String rawResponse = http.getString(); // Lấy toàn bộ chuỗi (có thể bị rác)
          
          // KỸ THUẬT TÁCH NỘI DUNG ĐẶC BIỆT
          int startIdx = rawResponse.indexOf("[[");
          int endIdx = rawResponse.indexOf("]]");

          if (startIdx != -1 && endIdx != -1) {
            // Lấy nội dung ở giữa [[ và ]]
            String cleanRes = rawResponse.substring(startIdx + 2, endIdx);
            cleanRes.trim(); // Xóa nốt khoảng trắng nếu còn

            if (cleanRes != "CLEAR" && cleanRes.length() > 0) {
              hasObstacle_AI = true;
              Serial.flush(); 
              Serial.println(""); // Ép xuống dòng mới hoàn toàn
              Serial.print(">>> AI XAC NHAN: "); 
              Serial.println(cleanRes); 
              Serial.println(""); // Kết thúc bằng một dòng trống để dễ nhìn 
            }
          }
        }
        http.end();
        esp_camera_fb_return(fb);
      }
    }
    vTaskDelay(200 / portTICK_PERIOD_MS); 
  }
}
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

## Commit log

2026-04-11 ver1 21/4 chạy nhận diện được người ghế loa kêu đc
    [Assem1.SLDASM, body.SLDPRT, bodyhead.SLDPRT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]
2026-05-27 bổ sung hướng dẫn dự án
    [body.SLDPRT, end.SLDPRT, end_2.SLDPRT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]
2026-05-27 chỉnh file main.ino
